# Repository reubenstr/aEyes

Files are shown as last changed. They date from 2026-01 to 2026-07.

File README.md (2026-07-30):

# aEyes

aEyes is a robotic face tracker with a set of six eyes tracking faces as they traverse the scene.

** Work in progress **

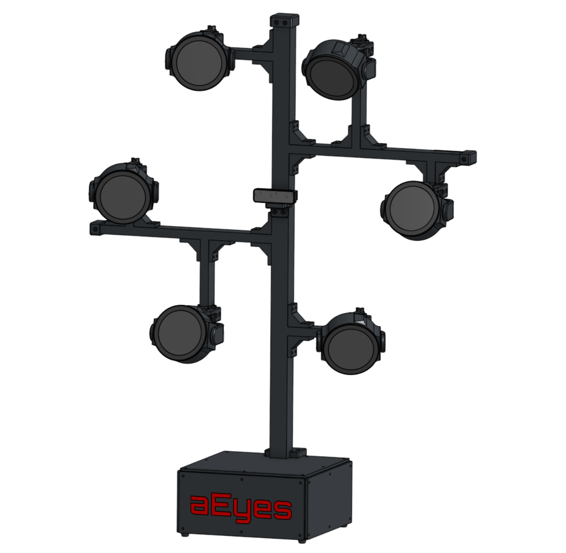
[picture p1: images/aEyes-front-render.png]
Front render


# Simulation

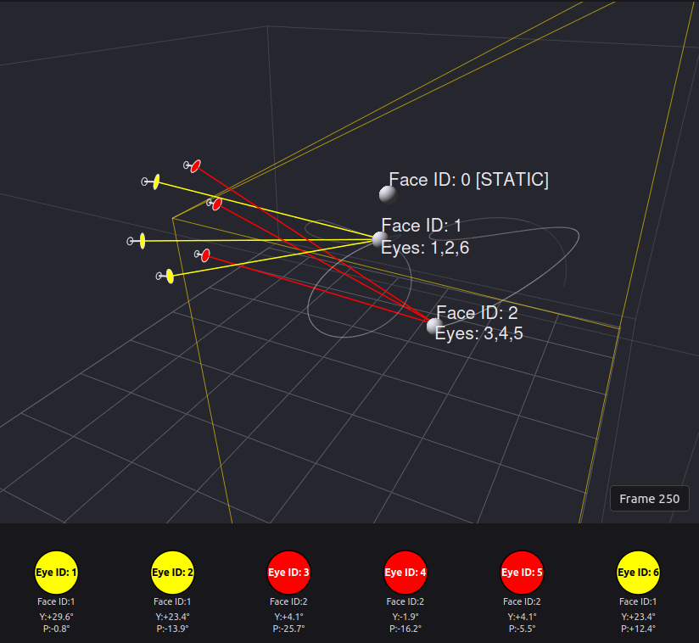
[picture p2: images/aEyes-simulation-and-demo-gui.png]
Simulation and demo GUI


The simulation (using PySide6 + pyqtgraph GUI) generates face positions moving through 3-space with some faces disappearing completely, disappearing and reappearing, or staying static. These faces are then sent through the face tracking, assignment, and eye manager pipeline to generate yaw and pitch of the indivdual eyes. 

# Pipeline

The pipeline is fairly straight forward and the major parts are: **AI Camera Interface → Face Tracker → Eye Manager → Message Publisher → RPi/LCD/Motors**

<figure>
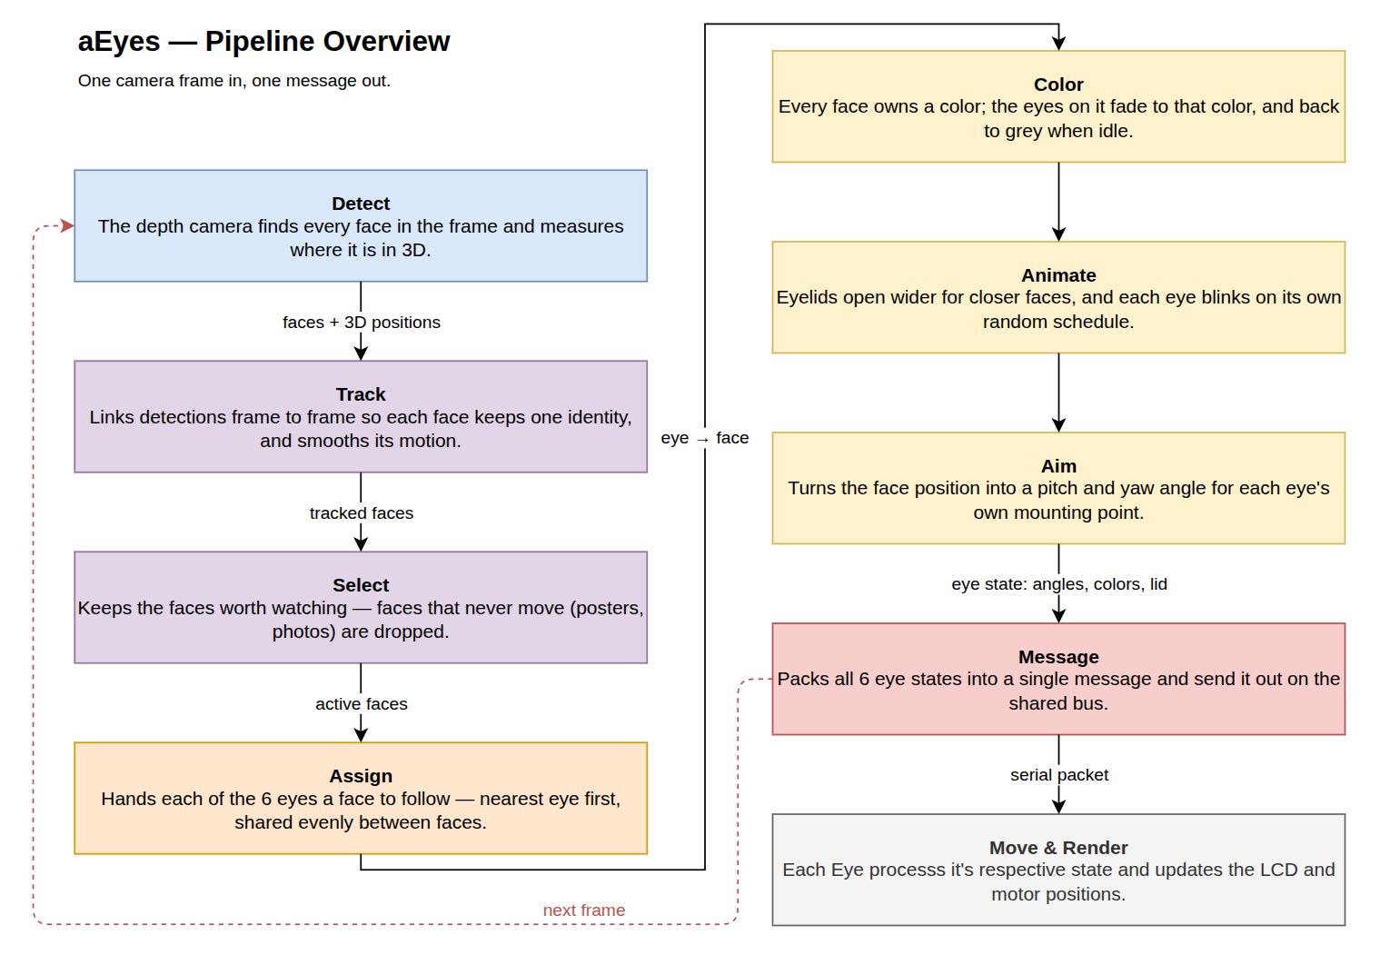
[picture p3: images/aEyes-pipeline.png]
  
  <figcaption align="center">Pipeline Simplified.</figcaption>
</figure>

# System

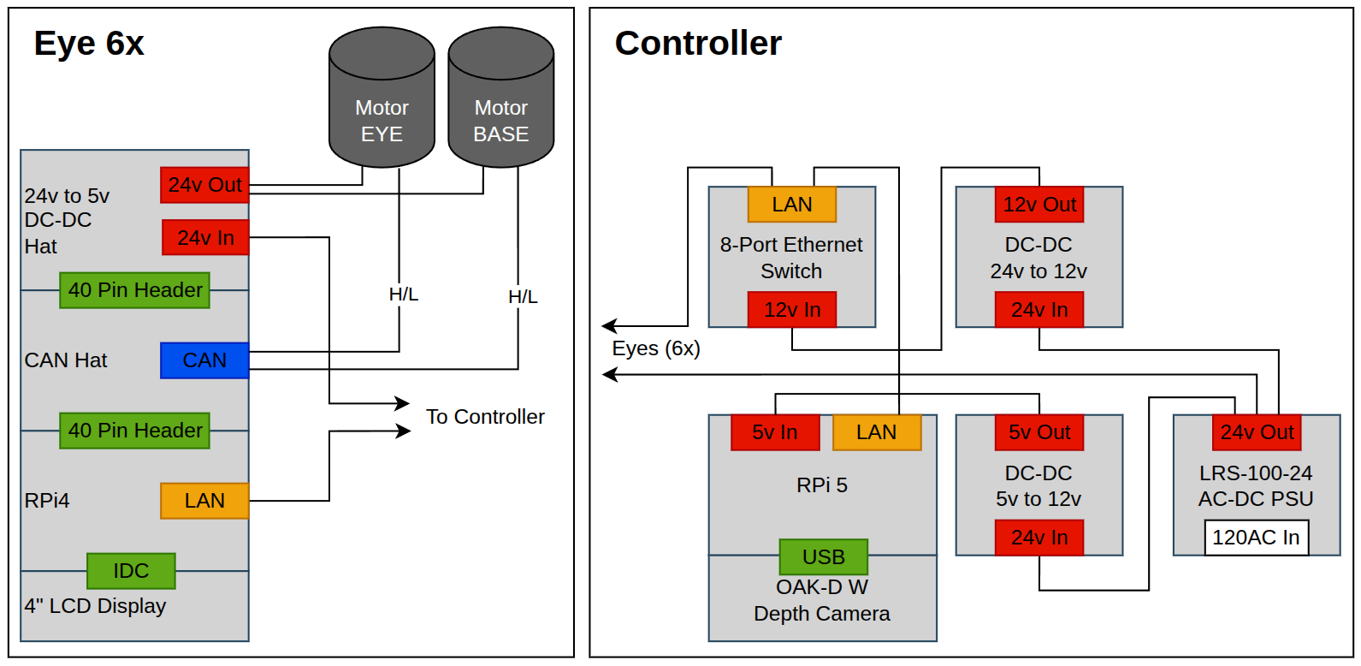
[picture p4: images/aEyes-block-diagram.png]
Block diagram


The system is split into two subsystems: a **Controller** and **6 Eye units**, all connected over a wired Ethernet network.

# Hardware

**Controller**
- Raspberry Pi 5
- OAK-D depth camera (USB)
- Mean Well LRS-100-24 AC/DC PSU (24V)
- DC-DC converter 24V → 12V
- 8-port Ethernet switch

**Eye units (×6)**
- Raspberry Pi 4B
- Waveshare 4" DSI LCD
- Waveshare RS485/CAN Hat
- DC-DC converter hat 24V → 5V
- 1× MG4010E-i10v3 CAN servo motor (yaw)
- 1× MG4005-v2 CAN servo motor (pitch)

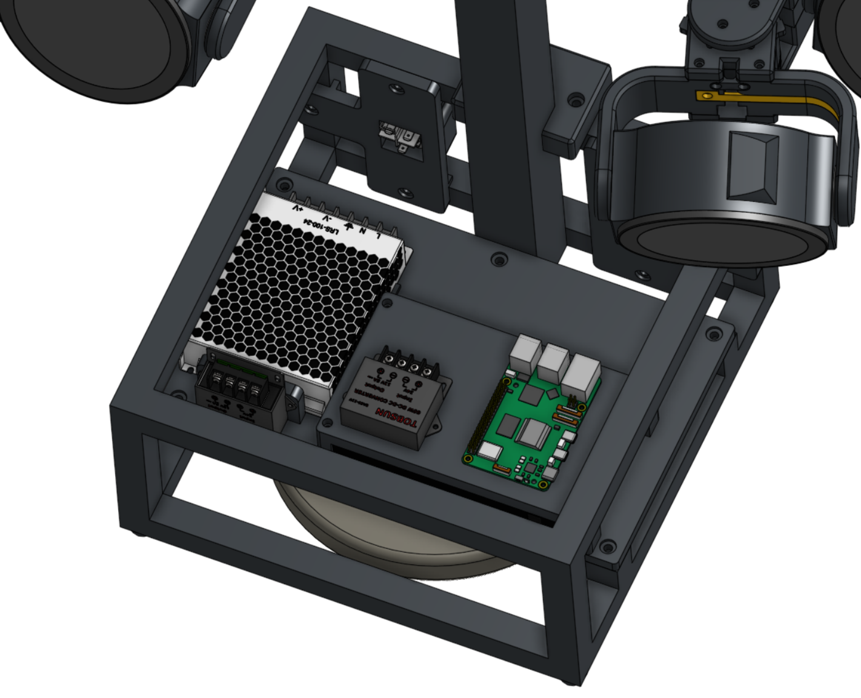
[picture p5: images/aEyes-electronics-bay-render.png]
Electronics bay


# Setup

There are several README's through out the repository for indivdual systems:

- [Controller](controller/README.md)
- [Eye](eye/README.md)
- [Extra Docs](docs/README.md)

# AI Disclosure

Project concept, aesthetic, engineering design, and original code base were conceived and executed by the author.

Portions of this codebase were reviewed, revised, and written with the assistance of Claude Code (Anthropic).

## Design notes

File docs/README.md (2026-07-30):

# Workflow

## Eyes

- Edit eye code on eye1.local
- use aEyes/scripts/pull-eye-code.sh to copy code from eye to controller
- use aEyes/scripts/sync-eye-code.sh to copy eye code from the controller to all eyes
- git commit / push as normal

# After Thoughts

Right now wires are running through the pitch rotation, but since pitch angle is typicall shallow there should not be too much stress on the wires. But, if there are communication issues or power issues, then a slip ring will need to be installed.

The motors are currently very expensive and there are alternatives such as RobStride EL05.

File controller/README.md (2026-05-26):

# Controller

Captures camera data and sends commands to the eyes.

## Installation

### Operating System

SD creation tool:
- https://www.raspberrypi.com/software/

Use the Raspberry Pi creation tool and apply OS customization with the following:
- Operating system: Raspberry Pi OS (64-bit) Desktop (Trixie)
- Hostname: aeyes
- Username/password: aeyes/aeyes
- Wifi credentials 
- Locale settings
- Enable SSH

If customization is not applied, setup the RPi using keyboard/monitor/mouse and use raspi-config to setup hostname, enable SSH, etc.

Update.
```bash
sudo apt update && sudo apt upgrade
```

Generate SSH keys. Use default options.
```bash
ssh-keygen
```

### Repo

Add key to gitlab.

Clone repo
```bash
cd ~
git clone git@github.com:reubenstr/aEyes.git
```

### Setup Controller
```bash
cd ~/aEyes/controller
```
Execute the installation script:
 
- Setups virtual environment
- Installs depenancies
- Apply static IP address to ethernet
- Installs services

```bash
./install.sh
```

## OAK-D W

Setup USB rules:

```bash
echo 'SUBSYSTEM=="usb", ATTRS{idVendor}=="03e7", MODE="0666"' | sudo tee /etc/udev/rules.d/80-movidius.rules
sudo udevadm control --reload-rules && sudo udevadm trigger
```

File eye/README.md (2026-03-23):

# EYE

This code creates the eye graphic and controls the motors.

Executed on each of the eye's Raspberry Pi 4.

## Hardware

- Raspberry Pi 4 B with 4GB RAM (but 2GB will likely work).
- https://www.raspberrypi.com/products/raspberry-pi-4-model-b/

Waveshare 4inch DSI LCD
- https://www.waveshare.com/4inch-dsi-lcd-c.htm
- https://www.waveshare.com/wiki/4inch_DSI_LCD_(C)

Waveshare RS485 CAN Hat
- https://www.waveshare.com/rs485-can-hat.htm
- http://www.waveshare.com/wiki/RS485_CAN_HAT

## Installation

### Operating System

Create a master SD card image that will be cloned for the remaining five RPis. The master will be configured as eye1 to start the process.

SD creation tool:
- https://www.raspberrypi.com/software/

Use the Raspberry Pi creation tool and apply OS customization with the following:
- Operating system: Raspberry Pi OS (64-bit) Desktop (Trixie)
- Hostname: eye1
- Username/password: eye/eye
- Wifi credentials 
- Locale settings
- Enable SSH

Connect the Pi to a keyboard/monitor and boot the Pi. 

Copy the controller's SSH keys to the RPi:
```bash
ssh-copy-id eye@eye1.local
```

Copy the Eye files:
```bash
rsync -av --progress ~/aEyes/eye eye@eye1.local:~/aEyes/
```

SSH into the RPi:
```bash
ssh eye@eye1.local
```

Run the install.sh script:
```bash
cd ~/aEyes/eye
sudo ./install.sh
```

The install script completes the following actions:
- Selects EYE_ID (user selected)
- sets the hostname
- resets the machine ID
- Configs the RPi firmware (overlays for LCD and CAN)
- Creates virtual environment
- Adds EYE_ID to .env
- Adds dev env vars to user's .bashrc
- Installs Python dependancies
- Enables low power mode
- Sets the desktop background image
- Hides the taskbar
- Installs services
- Configures ethernet static IP

Reboot the Pi:
```bash
sudo reboot
```

Verify the DSI LCD operates correctly and the PI is reachable over ethernet.

Turn off WiFi:
```bash
nmcli radio wifi off
```

Shutdown the PI:
```bash
sudo shutdown now
```

## Cloning

Clone the SD card after setup is complete:
```bash
sudo umount /dev/sda*
sudo dd if=/dev/sda of=~/master_eye.img bs=4M status=progress
sudo eject /dev/sda
```

Image the other five SD cards:
```bash
sudo umount /dev/sda*
sudo dd if=~/master_eye.img of=/dev/sda bs=4M status=progress conv=fsync
sudo eject /dev/sda
```

Boot up each RPi and run the install.sh script to setup unique EYE_ID per RPi. Use a keyboard/monitor or boot the RPis one at a time and ssh into eye@eye1.local.

## Mechanical

The main.py script will not initialize the motors if the .motors-zeroed file flag has not been found.

Use the zero.py script to zero the motors. When both motors have been zeroed the script will create the .motors-zered file flag allowing main.py to start

After the hardware is fully assembled and each RPi's software is configured, set the zero position of each motor.
Execute the zero.sh script per RPi.

## Development

ENV vars are required to start GUI on the RPi over SSH:

```bash
export DISPLAY=:0
export XAUTHORITY=/home/pi/.Xauthority
```

Since the main.sh is exected via a service, stop the service prior to manually executing main.sh

```bash
systemctl stop main.service
```

Manually start the eye's software.

```bash
cd aEyes/eye
sudo ./main.sh
```

### Misc. Commands and Notes

```bash
sudo ip link set can0 up type can bitrate 1000000
sudo ifconfig can0 txqueuelen 65536
sudo ifconfig can0 up
```

```bash
sudo systemctl status main.service
sudo journalctl -u main.service -f

```

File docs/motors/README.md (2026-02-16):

# Actuators

Model: MG4005 v2
Model: MG4010E-i10v3

Purchased from the Chinese company LingKong (Shanghai Lingkong Technology Co., Ltd.) also branded as LKMTECH 

LingKong products: http://en.lkmotor.cn/Product.aspx

Aliexpress: https://www.aliexpress.us/item/3256805950420462.html

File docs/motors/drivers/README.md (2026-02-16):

# Drivers

Windows drivers for CP210x USB to UART converter.

Source: https://www.silabs.com/software-and-tools/usb-to-uart-bridge-vcp-drivers?tab=downloads

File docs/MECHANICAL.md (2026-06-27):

# Mechanical

3D printed parts from PETG:
https://www.amazon.com/dp/B0FG3HMCVY

Frame: 2020 V-Slot (Euro Standard will work as well)

## Bolts

Motor to motor extension plate, bearing side: M3x12mm 6x
Motor to motor extension plate, drive side: M2.5x12mm 6x
Motor extention plate to u-channel, drive and bearing side: M3x12mm
2040 motor bracket to motor spacer, motor drive: M3x20mm 3x
2040 motor bracket to motor spacer, M3x8mm 3x

Center wire clip: 2x M3x6mm

U-Channel main: 4x M3x10 mm 
U-Channel wire clip: M3x8mm 
U-Channel stop block: 2x M3x8mm 

Eye:
    RPi hats: 4x M2.5x35 mm
    Motor - mounting side: 4x M3x6mm
    Motor - drive side: 3x M3x12 
    LCD to Front: 4x M4x12mm

Controller:
    Rpi: 4x M2.5x12mm

Base bracket to 2040
    Horiztonal - 8x M5x25mm
    Vertical - 

## Eye
    External
        Vertical: 8x M5x15mm
        Horizontal:  

    Eye Wires:        
        Power wires: 260mm + after sheath
        Ethernet: 250 + after sheath

        Motor wires:       
            Wire sheath - horizontal: 200mm
            Wire sheath - vertical - top: 200mm
            Wire sheath - vertical - bottom: 210mm

            Motor wires - Vertical mounts - 500mm from connector to tips  
            Motor wires - Horiztonal mounts - xxxmm from connector to tips

    Eye 2 starting 540mm wires

## Sheath

Braided sleeve 5mm inner diameter: 280mm (all eyes)

## Eye Positions

Looking at the frame from the observer's perspective: 1 is far left, then count clockwise 2...6 where six is not the lower left.

Network tag colors:
1: red
2: green
3: blue
4: yellow
5: red+green
6: blue+yellow

EYE_ID: Y (left/right), Z (up/down)

## Extrusions
  
See CAD model

## Wires

Motor for vertical orientation:
    Testing: 58cm from end of connectors

### MISC

Current motor wire length: 170mm

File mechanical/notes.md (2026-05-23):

# Mechanical

3D printed parts from PETG:
https://www.amazon.com/dp/B0FG3HMCVY

Frame: 2020 V-Slot (Euro Standard will work as well)

## Bolts

Motor to motor extension plate, bearing side: M3x12mm 6x
Motor to motor extension plate, drive side: M2.5x12mm 6x
Motor extention plate to u-channel, drive and bearing side: M3x12mm
2040 motor bracket to motor spacer, motor drive: M3x20mm 3x
2040 motor bracket to motor spacer, M3x8mm 3x

Center wire clip: 2x M3x6mm

U-Channel main: 4x M3x10 mm 
U-Channel wire clip: M3x8mm 
U-Channel stop block: 2x M3x8mm 

Eye:
    RPi hats: 4x M2.5x35 mm
    Motor - mounting side: 4x M3x6mm
    Motor - drive side: 3x M3x12 
    LCD to Front: 4x M4x12mm

Controller:
    Rpi: 4x M2.5x12mm

Base bracket to 2040
    Horiztonal - 8x M5x25mm
    Vertical - 

## Eye
    External
        Vertical: 8x M5x15mm
        Horizontal:  

    Eye Wires:        
        Power wires: 260mm + after sheath
        Ethernet: 250 + after sheath

        Motor wires:       
            Wire sheath - horizontal: 200mm
            Wire sheath - vertical - top: 200mm
            Wire sheath - vertical - bottom: 210mm

            Motor wires - Vertical mounts - 500mm from connector to tips  
            Motor wires - Horiztonal mounts - xxxmm from connector to tips

    Eye 2 starting 540mm wires

## Sheath

Braided sleeve 5mm inner diameter

1: 
2: 
3: 280mm
4: 
5: 
6: 

## Eye Positions

Looking at the frame from the observer's perspective: 1 is far left, then count clockwise 2...6 where six is not the lower left.

Network tag colors:
1: red
2: green
3: blue
4: yellow
5: red+green
6: blue+yellow

EYE_ID: Y (left/right), Z (up/down)

## Extrusions

2040:
    1x 1150.00mm
    2x 500.00mm
    2x 250.94mm
    2x 216.50mm
    2x 135.47mm
    Note: tolerance -+1mm is OK

2020:
    4x 260mm
    6x 300mm
    4x 100mm

## Wires

Motor for vertical orientation:
    Testing: 58cm from end of connectors

### MISC

current motor wire length: 170mm 

---------------------------------------------------------------

NEW NEW NEW

U-Channel to extension brackets:
    M3x12mm

2040:
    1x 1100.00mm
    2x 440.00mm
    2x 244.62mm
    2x 191.50mm   
    2x 137.81mm
    Note: tolerance -+1mm is OK

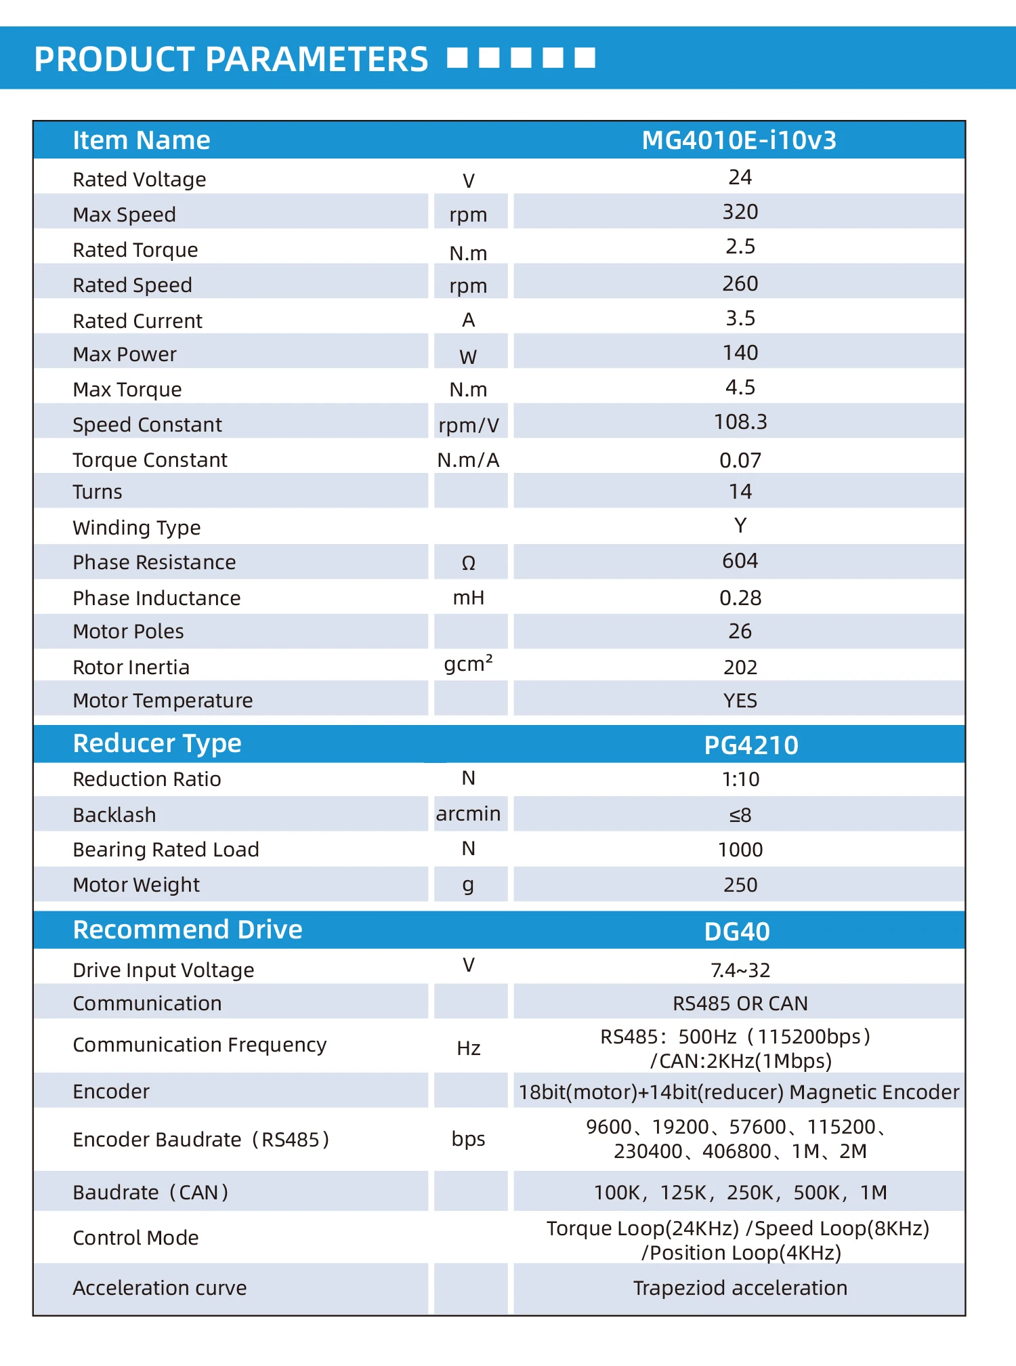
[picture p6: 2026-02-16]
docs/motors/MG4010E-specifications.webp

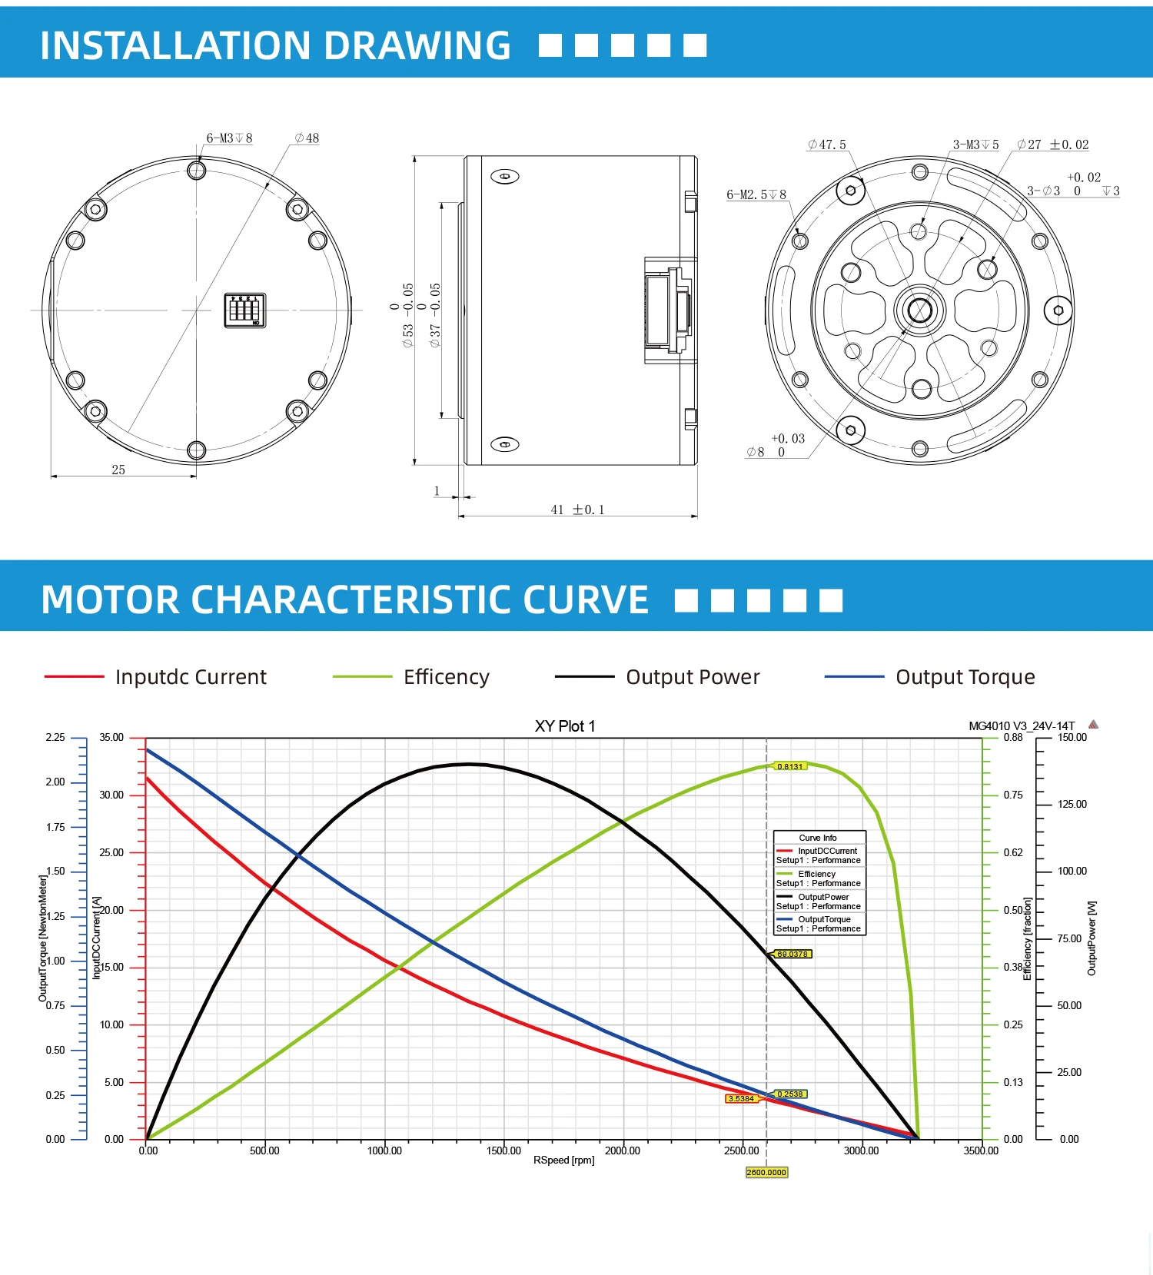
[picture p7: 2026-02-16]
docs/motors/MG4010E-dimensions.webp

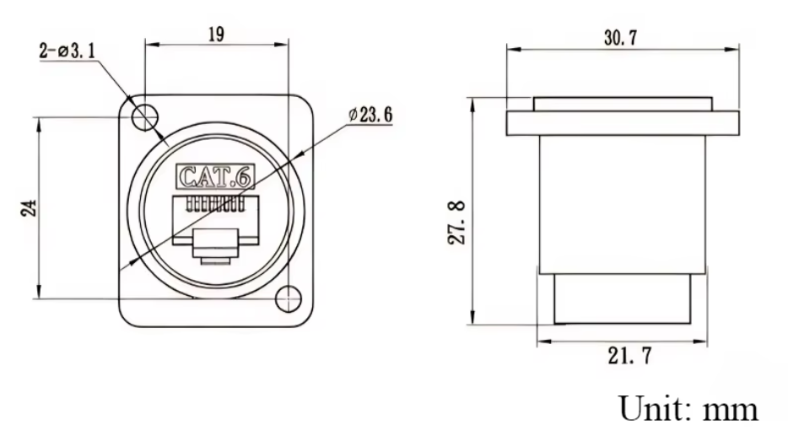
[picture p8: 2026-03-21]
docs/ethernet-bulkhead.png

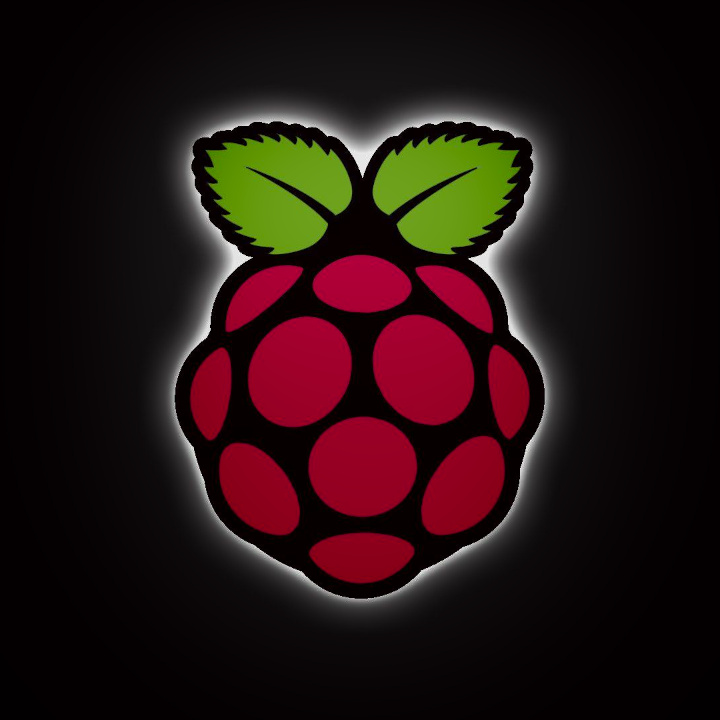
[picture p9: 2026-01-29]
eye/media/desktop.jpg

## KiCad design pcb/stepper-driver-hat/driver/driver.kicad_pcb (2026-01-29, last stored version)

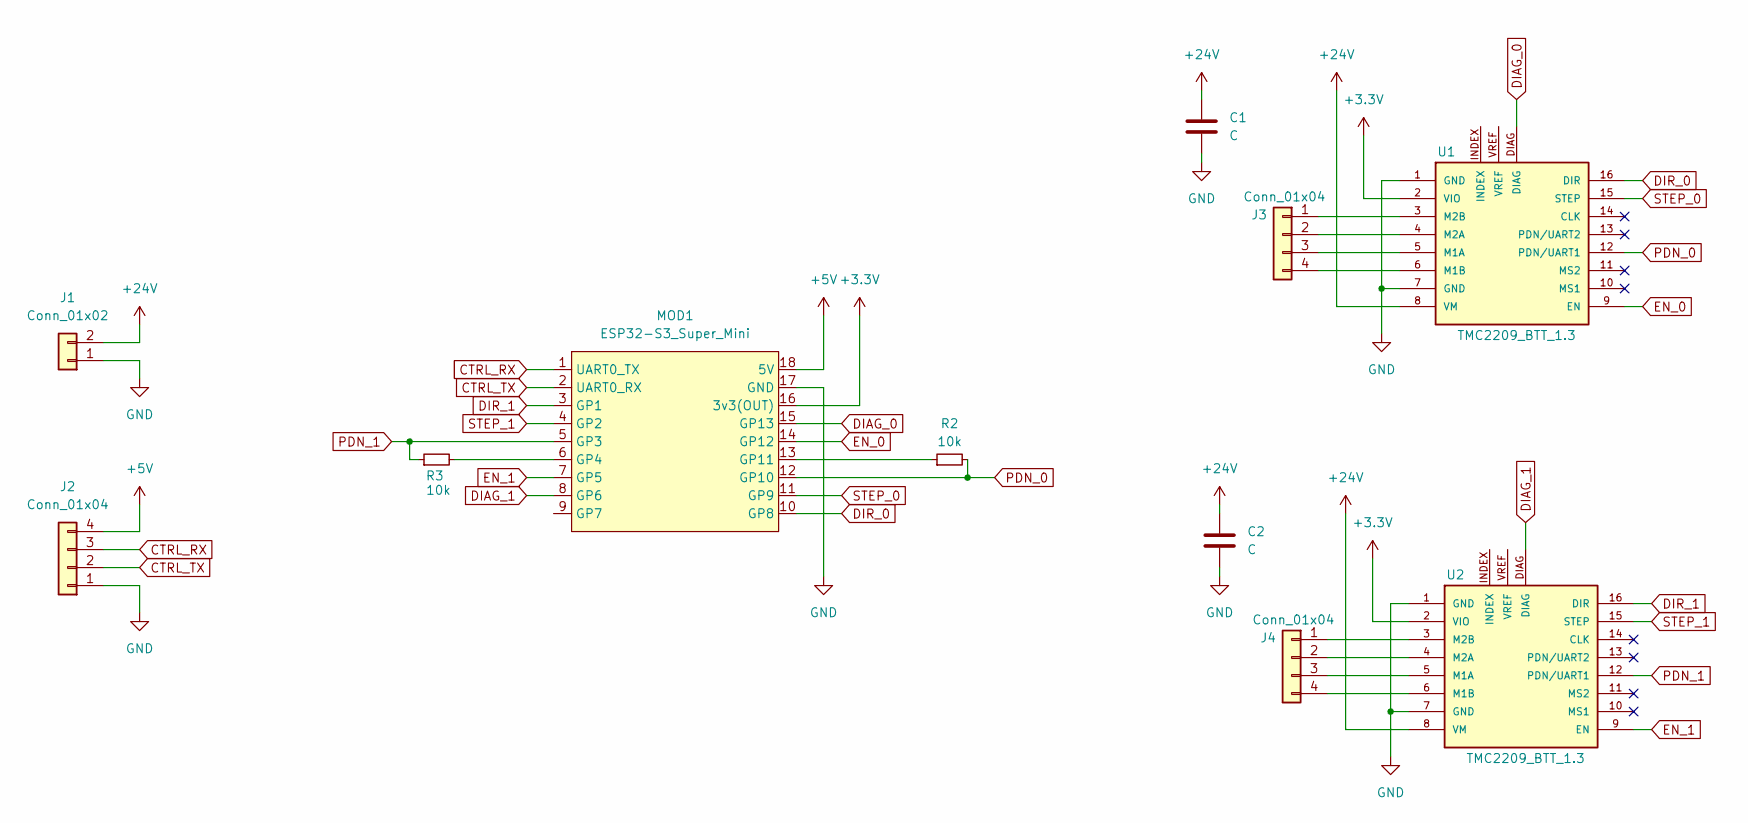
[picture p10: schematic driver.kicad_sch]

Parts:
C1, C2: C; CP_Radial_D10.0mm_P5.00mm
J1: Conn_01x02; PinHeader_1x02_P2.54mm_Vertical
J2, J3, J4: Conn_01x04; PinHeader_1x04_P2.54mm_Vertical
MOD1: ESP32-S3_Super_Mini; ESP32-S3 Super Mini
R2, R3: 10k; R_1206_3216Metric
U1, U2: TMC2209_BTT_1.3; MODULE_TMC2208_TMC2209

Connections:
+3.3V: MOD1.16 (3v3(OUT)), U1.2 (VIO), U2.2 (VIO)
+5V: J2.4, MOD1.18 (5V)
+24V: C1.1, C2.1, J1.2, U1.8 (VM), U2.8 (VM)
CTRL_RX: J2.3, MOD1.1 (UART0_TX)
CTRL_TX: J2.2, MOD1.2 (UART0_RX)
DIAG_0: MOD1.15 (GP13), U1.DIAG
DIAG_1: MOD1.8 (GP6), U2.DIAG
DIR_0: MOD1.10 (GP8), U1.16 (DIR)
DIR_1: MOD1.3 (GP1), U2.16 (DIR)
EN_0: MOD1.14 (GP12), U1.9 (EN)
EN_1: MOD1.7 (GP5), U2.9 (EN)
GND: C1.2, C2.2, J1.1, J2.1, MOD1.17 (GND), U1.1 (GND), U1.7 (GND), U2.1 (GND), U2.7 (GND)
unnamed: J3.1, U1.3 (M2B)
unnamed: J3.2, U1.4 (M2A)
unnamed: J3.3, U1.5 (M1A)
unnamed: J3.4, U1.6 (M1B)
unnamed: J4.1, U2.3 (M2B)
unnamed: J4.2, U2.4 (M2A)
unnamed: J4.3, U2.5 (M1A)
unnamed: J4.4, U2.6 (M1B)
unnamed: MOD1.6 (GP4), R3.2
unnamed: MOD1.13 (GP11), R2.1
PDN_0: MOD1.12 (GP10), R2.2, U1.12 (PDN/UART1)
PDN_1: MOD1.5 (GP3), R3.1, U2.12 (PDN/UART1)
STEP_0: MOD1.11 (GP9), U1.15 (STEP)
STEP_1: MOD1.4 (GP2), U2.15 (STEP)

Board: 2 copper layers, 11 parts (0 on the bottom side), 26 nets, no tracks yet.

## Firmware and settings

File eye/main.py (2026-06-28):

import os
import signal
import sys
import zmq
import json
from eye_renderer import EyeRenderer, TextType
from threading import Thread, Event
from time import sleep, time

from data_types import ControlMessage
from motors.data_types import MotorName, MotorSpeeds
from motors.motors import Motors
from motors.motor_config import get_motor_info, BASE_HOME_INVERSION, EYE_INVERSIONS

SOCKET_ADDRESS = "192.168.5.100"
SOCKET_PORT = 9000
MESSAGE_TIMEOUT_SECONDS = 3.0
CONTROLLER_FPS = 15

class Eye:
    def __init__(self):
        self.eye_id = None
        self.motors = None
        self.socket = None
        self.thread_handle = None
        self.commanded_yaw = 0.0
        self.commanded_pitch = 0.0

    ###############################################################################
    # Initializers
    ###############################################################################

    def init_eye_renderer(self):
        print("[Main] init eye renderer")
        self.eye_renderer = EyeRenderer()
        self.eye_renderer.window.on_close = self.shutdown
        self.eye_renderer.set_text(TextType.INFO, "Waiting for data.")

    def _init_local(self):
        print("[Main] initialize local variables")
        eye_id = os.getenv("EYE_ID", None)
        if eye_id is None:
            self.eye_renderer.set_text(TextType.ERROR, "EYE_ID not found in ENV vars!")
        else:
            self.eye_id = int(eye_id)

    def _init_motors(self):
        print("[Main] initialize motors")

        self.motors = Motors(allow_enable=True)

        if self.eye_id and EYE_INVERSIONS[self.eye_id] is True:
            self.motors.set_inversion_rotation(MotorName.BASE, not self.motors.get_inverse_rotation(MotorName.BASE))
            self.motors.set_inversion_rotation(MotorName.EYE, not self.motors.get_inverse_rotation(MotorName.EYE))
            sleep(0.5) # Allow repolling (recalcuation) of positions that may of been inversed.

        self.motors.enable_all_motors()
        self.home_motors(self.motors)
     

    def _init_socket(self):
        print("[Main] init zmq")
        context = zmq.Context()
        self.socket = context.socket(zmq.SUB)
        address = f"tcp://{SOCKET_ADDRESS}:{SOCKET_PORT}"
        self.socket.connect(address)
        self.socket.setsockopt_string(zmq.SUBSCRIBE, "")
        print(f"[Main] Socket requested at address: {address}")

    ###############################################################################
    # Helpers
    ###############################################################################

    def _flush_socket(self):
        try:
            while True and self.socket is not None:
                self.socket.recv_string(flags=zmq.NOBLOCK)
        except zmq.Again:
            pass

    def ramp_target(self, commanded: float, target: float) -> float:
        CLOSE_DEG = 5.0  # below this → pass-through (fast tracking)
        FAR_DEG = 30.0  # above this → max slowdown
        FAST_DEG_S = 900.0  # deg/sec when close (~pass-through)
        SLOW_DEG_S = 22.5  # deg/sec when far   (smooth slew)
        delta = abs(target - commanded)
        t = max(0.0, min(1.0, (delta - CLOSE_DEG) / (FAR_DEG - CLOSE_DEG)))
        t = 3 * t**2 - 2 * t**3  # smoothstep
        max_step = (FAST_DEG_S + t * (SLOW_DEG_S - FAST_DEG_S)) / CONTROLLER_FPS
        return commanded + max(-max_step, min(max_step, target - commanded))

    ###############################################################################
    # Motor Utilities
    ###############################################################################

    def home_motors(self, motors: Motors):
        """
        Home both motors by moving into the physical endstop and polling for position halt.
        """

        motor_home_target_pos_offset = 180
        motors_to_home = [MotorName.BASE, MotorName.EYE]
        operation_timeout_seconds = 5.0
        home_duration = 0.5  # Time motor is required to be stopped before considered home.
        home_threshold_deg = 0.25
        prev_positions = {motor: motors.get_motor_position(motor) for motor in motors_to_home}
        home_started: dict[MotorName, float | None] = {motor: None for motor in motors_to_home}
        homed = {motor: False for motor in motors_to_home}

        self.eye_renderer.set_text(TextType.INFO, "Homing motors...")

        base_position = motors.get_motor_position(MotorName.BASE)    
        base_home_target_position = (
            -motor_home_target_pos_offset if self.eye_id is not None and BASE_HOME_INVERSION[self.eye_id] is True else motor_home_target_pos_offset
        )    
        eye_home_target_position = motor_home_target_pos_offset
        motors.set_enforce_position_limits(MotorName.BASE, False)
        motors.set_motor_targets(motor_name=MotorName.BASE, speed=MotorSpeeds.SLOW, position=base_position + base_home_target_position)

        eye_position = motors.get_motor_position(MotorName.EYE)
        motors.set_enforce_position_limits(MotorName.EYE, False)
        motors.set_motor_targets(motor_name=MotorName.EYE, speed=MotorSpeeds.SLOW, position=eye_position + eye_home_target_position)

        sleep(0.5)  # Allow motors to begin moving before polling.

        start = time()
        while time() - start < operation_timeout_seconds:
            for motor_name in (m for m in motors_to_home if not homed[m]):
                pos = motors.get_motor_raw_position(motor_name)
                delta = abs(pos - prev_positions[motor_name])
                prev_positions[motor_name] = pos

                if motor_name is MotorName.BASE:
                    print(f"{motor_name}: {pos}")

                started = home_started[motor_name]
                if delta < home_threshold_deg:
                    if started is None:
                        home_started[motor_name] = time()
                    elif time() - started >= home_duration:
                        homed[motor_name] = True
                else:
                    home_started[motor_name] = None

            if all(homed.values()):
                break

            sleep(0.050)

        home_position = get_motor_info(MotorName.BASE).home_position
        raw_pos = motors.get_motor_raw_position(MotorName.BASE)
        pos = motors.get_motor_position(MotorName.BASE)
    
        if self.eye_id is not None and BASE_HOME_INVERSION[self.eye_id] is True:
            offset = -raw_pos - home_position
        else:
            offset = -raw_pos + home_position          

        motors.set_enforce_position_limits(MotorName.BASE, True)
        motors.set_position_offset(MotorName.BASE, offset)
        motors.set_motor_targets(motor_name=MotorName.BASE, speed=MotorSpeeds.SLOW, position=0)

        home_position = get_motor_info(MotorName.EYE).home_position
        raw_pos = motors.get_motor_raw_position(MotorName.EYE)
        offset = -(raw_pos - home_position)
        motors.set_enforce_position_limits(MotorName.EYE, True)
        motors.set_position_offset(MotorName.EYE, offset)
        motors.set_motor_targets(motor_name=MotorName.EYE, speed=MotorSpeeds.SLOW, position=0)
       
        sleep(3)  # Allow motors to reach the home position before exiting. 
    

    ###############################################################################
    # Thread
    ###############################################################################

    def _start(self):
        print(f"[Main] worker thread starting")
        self.exit_event: Event = Event()
        self.thread_handle = Thread(target=self._worker)
        self.thread_handle.start()

    def stop(self):
        print(f"[Main] worker thread stoping")
        if self.thread_handle and self.thread_handle.is_alive():
            self.exit_event.set()
            self.thread_handle.join()

    def _worker(self):
        self.exit_event.clear()
        last_msg_time = time()
        connected = False
        self.eye_renderer.set_text(TextType.INFO, "Waiting for data")
        self._flush_socket()

        while not self.exit_event.is_set():
            if self.socket:
                try:
                    msg_raw = self.socket.recv_string(flags=zmq.NOBLOCK)
                    msg_json = json.loads(msg_raw)

                    if self.eye_id is not None:
                        if str(self.eye_id) not in msg_json:
                            print(f"[Main] WARNING: eye_id {self.eye_id} not found in message.")
                            self.eye_renderer.set_text(TextType.ERROR, f"Eye ID {self.eye_id} not found in message!")
                        else:
                            msg = ControlMessage(**msg_json[str(self.eye_id)])

                            last_msg_time = time()
                            if not connected:
                                connected = True
                                print("[Main] Controller connected.")

                            self.eye_renderer.set_text(TextType.INFO, "")
                            self.eye_renderer.set_radius(msg.radius)
                            self.eye_renderer.set_rotation_deg(msg.rotation_deg)
                            self.eye_renderer.set_eye_lid_position(msg.eye_lid_position)
                            self.eye_renderer.set_iris_color_rgb255(msg.iris_color)
                            self.eye_renderer.set_striation_color_rgb255(msg.striation_color)
                            self.eye_renderer.set_is_cat_eye(msg.is_cat_eye)

                            if self.motors:
                                self.commanded_yaw = self.ramp_target(self.commanded_yaw, msg.yaw)
                                self.commanded_pitch = self.ramp_target(self.commanded_pitch, msg.pitch)
                                self.motors.set_motor_targets(motor_name=MotorName.BASE, speed=MotorSpeeds.FAST, position=self.commanded_yaw)
                                self.motors.set_motor_targets(motor_name=MotorName.EYE, speed=MotorSpeeds.FAST, position=self.commanded_pitch)

                except zmq.Again:
                    if connected and time() - last_msg_time > MESSAGE_TIMEOUT_SECONDS:
                        connected = False
                        print("[Main] Controller disconnected (timeout).")
                        self.eye_renderer.set_text(TextType.ERROR, "Data timeout!")
                except (json.JSONDecodeError, TypeError, KeyError) as e:
                    print(f"[Main] Bad message: {e}")

            sleep(0.005)

    ###############################################################################
    # General
    ###############################################################################

    def _deferred_init(self):
        sleep(0.3)  # Allow pyglet event loop to render first frame
        self._init_local()
        if self.eye_id:
            self._init_motors()
            self._init_socket()
            self._start()

    def run(self):
        self.init_eye_renderer()
        Thread(target=self._deferred_init, daemon=True).start()

        # Blocking
        self.eye_renderer.run()

    def shutdown(self):
        self.stop()
        if self.motors:
            try:
                self.motors.shutdown()
            except Exception as e:
                print(f"[Main] Error shutting down motors: {e}")
        try:
            self.eye_renderer.shutdown()
        except Exception as e:
            print(f"[Main] Error shutting down renderer: {e}")


###############################################################################
# Main Entry
###############################################################################
if __name__ == "__main__":
    eye = Eye()
    signal.signal(signal.SIGTERM, lambda sig, frame: (eye.shutdown(), sys.exit(0)))
    try:
        eye.run()
    except KeyboardInterrupt:
        eye.shutdown()

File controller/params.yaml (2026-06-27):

# Behavioral parameters for the aEyes controller.
# Edit this file to tune the system without touching Python source.
# Physical/geometric constants (eye positions, pivot offsets, FOV) live in config.py.

# ---------------------------------------------------------------------------
# System timing
# ---------------------------------------------------------------------------
system:
  refresh_rate_hz: 15        # Main loop publish rate [Hz]. Higher = more CPU, lower = laggier.

# ---------------------------------------------------------------------------
# Network / ZMQ publisher
# ---------------------------------------------------------------------------
publisher:
  socket_port: 9000          # ZMQ PUB port. Must match SOCKET_PORT on all Pi eye units.
  socket_address: "*"        # Bind address. "*" = all interfaces.

# ---------------------------------------------------------------------------
# Face tracker — matching gate
# ---------------------------------------------------------------------------
tracker:
  base_max_distance: 0.4     # Match gate radius at 1m depth [m].  range: 0.1–1.0
  depth_scale_factor: 0.15   # Gate growth per meter of depth [m/m].  range: 0.0–0.5
  embedding_weight: 0.3      # 0=position-only matching, 1=embedding-only.  range: 0–1

  # Track lifecycle (all in frames)
  min_hits_to_confirm: 30                      # Frames before tentative -> confirmed.  range: 1-60
  min_hits_to_confirm_reacquiring_tracks: 30   # Frames before reacquiring -> confirmed.  range: 1-60
  max_missing_confirmed: 30                    # Frames a confirmed track survives without detection.  range: 5-30
  max_missing_tentative: 5                     # Frames a tentative track survives without detection.  range: 1-5

  # Re-identification
  reid_window_frames: 45     # Frames a lost track is retained for re-ID.  range: 10–60
  reid_max_distance: 1.0     # Spatial search radius for re-ID matching [m].  range: 0.5–2.0

  # Output smoothing
  ema_alpha: 0.4             # EMA smoothing on output position. Lower = smoother, laggier.  range: 0–1
  embedding_ema_keep: 0.7    # Weight of existing embedding in running average.  range: 0–1
                             # New embedding weight = 1 - embedding_ema_keep.

  # Static-face detection — faces whose rolling-max Kalman speed stays below
  # static_speed_thresh_mps for static_window consecutive matched frames are
  # classified as static and excluded from eye assignment.
  static_window: 1000            # Rolling velocity window length [frames].  range: 30–1000
  static_speed_thresh_mps: 0.15  # Max speed to be considered static [m/s].  range: 0.01–1.0

# ---------------------------------------------------------------------------
# Kalman filter (3D constant-velocity)
# ---------------------------------------------------------------------------
kalman:
  process_noise: 0.1         # Process noise (q). Higher = tracks react faster but noisier.
  measurement_noise_xy: 0.05 # X/Y position measurement noise [m]. Lower = trust sensor more.
  measurement_noise_z: 0.20  # Depth measurement noise [m]. Higher = trust depth less.

# ---------------------------------------------------------------------------
# Eye assigner
# ---------------------------------------------------------------------------
assigner:
  assign_interval_s: 0.5     # Min seconds between assigning extra eyes to already-covered faces.

# ---------------------------------------------------------------------------
# Eye manager — animation
# ---------------------------------------------------------------------------
eye_manager:
  color_in_rate: 2.0         # Lerp speed toward face color [units/s]. Higher = faster.
  color_out_rate: 4.0        # Lerp speed back toward grey [units/s].
  blink_rate: 1.0            # Blink animation speed on new face assignment [blinks/s].

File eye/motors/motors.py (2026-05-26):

#!/usr/bin/env python
import os
import can
import sys
import traceback
import subprocess
from time import time, sleep
from rich import print  # Overrides print and injects colors
from threading import Thread, Event, Lock
from typing import Dict, List

from motors.motor import Motor
from motors.motor_config import motor_config
from motors.data_types import CanInfo, MotorZeroInfo, Status, MotorName


"""
    Controls a collection of MG4010E-i10v3 actuators on a multiple CAN bus networks.
"""

class Motors:
    def __init__(self, allow_enable: bool):
        self.allow_enable: bool = allow_enable
        self.tag: str = "Motors"

        self.thread_handle = None
        self.exit_event = Event()
        self.data_lock = Lock()

        self.motors_enabled: bool = False
        self.motor_enable_sequence_delay_seconds: float = 0.250
        self.motor_disable_sequence_delay_seconds: float = 0.250     

        self.min_loop_rate_seconds: float = 0.010

        can_channels = list({motor.can_channel for motor in motor_config() if motor.allow_motion or motor.allow_comms})
        self.can_infos: Dict[str, CanInfo] = {}
        for can_channel in can_channels:
            self.can_infos[can_channel] = CanInfo(
                can_channel=can_channel,
                bus=None,
                status=Status.STANDBY,
                thread_handle=None,
                exit_event=Event(),
                lock=Lock(),
            )
        self.init_can_buses(self.can_infos)

        self.motors: Dict[str, Motor] = {}
        self.target_positions: Dict[str, float] = {}
        self.target_speeds: Dict[str, int] = {}

        default_speed: int = 250

        for motor in motor_config():
            if motor.can_channel in can_channels:
                self.motors[motor.name] = Motor(
                    name=motor.name,
                    motor_id=motor.id,
                    min_position=motor.min_position,
                    max_position=motor.max_position,
                    inverse_rotation=motor.inverse_rotation,
                    allow_comms=motor.allow_comms,
                    allow_motion=motor.allow_motion,
                    can_channel=motor.can_channel,
                    bus=self.can_infos[motor.can_channel].bus,              
                )
                self.target_positions[motor.name] = 0  # Will be set during enable.
                self.target_speeds[motor.name] = default_speed

        self.worker_startup_timeout_seconds: float = 5.0    
        self._start()

    ###############################################################################
    # CAN
    ###############################################################################

    def init_can_buses(self, can_infos: Dict[str, CanInfo]):

        self.deinit_can_buses(can_infos)

        for can_info in can_infos.values():
            print(f"[{self.tag}] upping {can_info.can_channel} interface")

            result = subprocess.run(
                f"sudo ip link set {can_info.can_channel} up type can bitrate 1000000",
                shell=True,
                capture_output=True,
                text=True,
            )

            if result.returncode == 0:
                print(f"[{self.tag}] initializing {can_info.can_channel}  bus")
                try:
                    # USB CAN using this firmware:
                    # https://canable.io/getting-started.html#alt-firmware
                    # https://canable.io/updater/canable2.html
                    can_info.bus = can.interface.Bus(interface="socketcan", channel=can_info.can_channel, bitrate=1000000)
                except:
                    print(f"[{self.tag}] error, unable to init {can_info.can_channel}!")
                    can_info.status = Status.ERROR
                    continue

            else:
                print(f"[{self.tag}] error, failed to up {can_info.can_channel}!")
                can_info.status = Status.ERROR
                continue

            sleep(1)     
            can_info.status = Status.ACTIVE

    def deinit_can_buses(self, can_infos: Dict[str, CanInfo]):
        for can_info in can_infos.values():
            # if can_info.status == Status.ACTIVE:
            print(f"[{self.tag}] deinitializing {can_info.can_channel}")
            try:
                if can_info.bus:
                    can_info.bus.shutdown()
                    can_info.status = Status.STANDBY
            except:
                print(f"[{self.tag}] error deinitializing {can_info.can_channel}!")

            print(f"[{self.tag}] downing {can_info.can_channel} interface")
            os.system(f"sudo ifconfig {can_info.can_channel} down")

    ###############################################################################
    # Per Motor
    ###############################################################################

    def set_zero_to_current_position(self, motor_name: str):
        """Zero requires power cycle to take effect!"""        
        motor = self.motors[motor_name]
        success = motor.cmd_set_zero_to_current_pos()     
        return success

    ###############################################################################
    # All Motors
    ###############################################################################

    def enable_all_motors(self):
        max_attempts = 3
        start = time()
        self.acquire_can_locks()
        for motor in self.motors.values():
            if self.allow_enable and motor.allow_motion:
                print(f"[{self.tag}] enabling motor: {motor.name}")
                attempt = 0
                while True:
                    if motor.cmd_motor_on():
                        break
                    else:
                        attempt += 1
                        print(f"[{self.tag}][ALL] error, failed to enable {motor.name}, attempt number {attempt}!")
                        if attempt > max_attempts:
                            self.motors_enabled = False                         
                            self.release_can_locks()
                            return False
                        sleep(self.motor_enable_sequence_delay_seconds)

                sleep(self.motor_enable_sequence_delay_seconds)
        print(f"[{self.tag}][ALL] enable all motors on completed, time: {time() - start:0.3f}")
        self.motors_enabled = True     
        self.release_can_locks()
        return True
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

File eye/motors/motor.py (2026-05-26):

import os
import can
from rich import print
from can.interface import Bus
from typing import Optional

from .data_types import MotorName

"""
    Motor:
        mg4010e-i10-v3

    Info link:
        https://wiki.openelab.io/lkmtech/mg4010e-i10-v3-dual-encoder-robot-motor

    Docs:
        See docs directory for datasheets, drawings, etc.

    Basic specs:
        Rated torque: 2.5Nm
        Rated speed: 260rpm
        Rated voltage: 24V
        Rated current: 3.5A
        Communication: CAN
        Encoders: Dual (motor shaft and output shaft)
        Gearbox: 1:10 reduction ratio
        Weight: 250g

    Hardware driver notes:
        Does not contain a min and max position, there software is required to check for physical limits.
        
        CAN is not able to set the torque limit, speed limit, etc. Only the UART interface is capable
        of setting these parameters. The torque limit is used to create 'compliance'. A best guess is implemented.
    
    Software driver Notes:
        Upon startup the motor driver reports angles 0 to 360 degrees.
        To prevent issues of wrong initial directions, this library
        uses a -180 to 180 convention.
        Start up angles > 180 flag an offset to match the desired convention.

        Pid params are saved in RAM and must be applied after each power cycle.
"""


class Motor:
    def __init__(
        self,
        name: MotorName,
        motor_id: int,
        min_position: float,
        max_position: float,
        inverse_rotation: bool,
        allow_comms: bool,
        allow_motion: bool,
        can_channel: str,
        bus: Bus,
    ):
        self.name: MotorName = name
        self.motor_id: int = motor_id
        self.min_position: float = min_position
        self.max_position: float = max_position
        self.inverse_rotation: bool = inverse_rotation
        self.allow_comms: bool = allow_comms
        self.allow_motion: bool = allow_motion
        self.can_channel: str = can_channel
        self.bus: Bus = bus

        self.tag = f"[Motor][{name}]"
        self.prints_enabled: bool = False

        # Motor states (from motor driver):
        self.temperature: int = 0
        self.voltage: float = 0
        self.current: float = 0
        self.motor_speed: int = 0
        self.encoder_position: int = 0
        self.raw_position_degrees: float = 0
        self.position_degrees: float = 0

        # Motor fault states (from motor driver):
        self.under_voltage_protection: bool = False
        self.over_voltage_protection: bool = False
        self.over_temperature_protection: bool = False
        self.lost_input_protection: bool = False

        # Motor states:
        self.enabled: bool = False
  
        # Communication states:
        self.send_error: bool = False
        self.reply_timeout_seconds: float = 0.050
        self.reply_timeout_count: int = 0

        # Driver config:
        self.angle_pid_kp: int = 5  # Position loop, default: 100
        self.angle_pid_ki: int = 5  # Position loop, default: 100
        self.speed_pid_kp: int = 50  # Speed loop, default: 50
        self.speed_pid_ki: int = 40  # Speed loop, default: 40
        self.iq_pid_kp: int = 50  # Torque loop, default: 50
        self.iq_pid_ki: int = 50  # Torque loop, default: 50

        # Other config:
        self.position_offset: float = 0.0
        self.max_reply_timeouts_allow: int = 3
        self.enforce_position_limits: bool = True

        self.ARBITRATION_BASE_OFFSET: int = 0x140

    ###############################################################################
    # Operations
    ###############################################################################

    def op_can_send_message(self, motor_id: int, data: list):
        try:
            identifier = self.ARBITRATION_BASE_OFFSET + motor_id
            if self.prints_enabled:
                print(f"{self.tag} sending message, bus={self.bus.channel_info}, motor_id={motor_id}, arbitration_id=0x{identifier:X}, data={data}")
            msg = can.Message(is_extended_id=False, arbitration_id=identifier, data=data)
            self.bus.send(msg)
            self.send_error = False
            return True
        except Exception as e:
            self.send_error = True
            if self.prints_enabled:
                print(f"{self.tag}[op_can_send_message] {type(e).__name__} {e}")
            return False

    def op_wait_for_reply(self) -> Optional[can.Message]:
        reply = self.bus.recv(self.reply_timeout_seconds)
        if reply is None:
            self.reply_timeout_count += 1
        else:
            self.reply_timeout_count = 0
        return reply

    ###############################################################################
    # Commands
    ###############################################################################

    def cmd_motor_on(self):
        if not self.op_can_send_message(self.motor_id, [0x88, 0, 0, 0, 0, 0, 0, 0]):
            return False
        reply = self.op_wait_for_reply()
        success = reply and self.motor_id == reply.arbitration_id - self.ARBITRATION_BASE_OFFSET
        if success:
            self.enabled = True
        return success

    def cmd_motor_off(self):
        if not self.op_can_send_message(self.motor_id, [0x80, 0, 0, 0, 0, 0, 0, 0]):
            return False
        reply = self.op_wait_for_reply()
        success = reply and self.motor_id == reply.arbitration_id - self.ARBITRATION_BASE_OFFSET
        if success:
            self.enabled = False
        return success

    def cmd_motor_stop(self):
        if not self.op_can_send_message(self.motor_id, [0x81, 0, 0, 0, 0, 0, 0, 0]):
            return False
        reply = self.op_wait_for_reply()
        return reply and self.motor_id == reply.arbitration_id - self.ARBITRATION_BASE_OFFSET

    def cmd_clear_motor_errors(self):
        if not self.op_can_send_message(self.motor_id, [0x9B, 0, 0, 0, 0, 0, 0, 0]):
            return False
        reply = self.op_wait_for_reply()
        return reply and self.motor_id == reply.arbitration_id - self.ARBITRATION_BASE_OFFSET

    def cmd_set_zero_to_current_pos(self):
        if not self.op_can_send_message(self.motor_id, [0x19, 0, 0, 0, 0, 0, 0, 0]):
            return False
        reply = self.op_wait_for_reply()
        return reply and self.motor_id == reply.arbitration_id - self.ARBITRATION_BASE_OFFSET

    def cmd_set_pid_to_ram(self, angle_kp: int, angle_ki: int, speed_kp: int, speed_ki: int, iq_kp: int, iq_ki: int):
        """
        Sets PID parameters to RAM; invalid upon power cycle.
        """
        if not self.op_can_send_message(self.motor_id, [0x34, 0, angle_kp, angle_ki, speed_kp, speed_ki, iq_kp, iq_ki]):
            print("[Motor] failed to send pid to motor!")
        reply = self.op_wait_for_reply()
        return reply and self.motor_id == reply.arbitration_id - self.ARBITRATION_BASE_OFFSET
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

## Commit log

2026-01-22 sauron working - but going to revert to eye
    [main.py]
2026-01-24 pcb schem update
    [stepper-driver-hat.kicad_pcb, stepper-driver-hat.kicad_sch]
2026-01-25 motor test
2026-01-27 esp32 comm started
    [driver.kicad_pcb, driver.kicad_sch, stepper-driver-hat.kicad_sch]
2026-01-27 stepper driver update
2026-01-28 frag cleanup, better blink, cat eye shadow fix
    [controller.py]
2026-01-29 add motor commands to messages
2026-01-29 firmeware update
    [driver.kicad_pcb, driver.kicad_sch]
2026-02-02 can motor test success
2026-02-16 update motors
2026-02-17 remove old firmware, etc.
    [driver.kicad_pcb, driver.kicad_sch, stepper-driver-hat.kicad_pcb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]
2026-02-25 building classes, data flowing crudely
2026-02-26 clean up; pre add gimbal arm transform
2026-02-26 gimbal arm t added and appears to be working
2026-03-10 managers: refactor EyeState, add striation color, blink, and Python 3.12 type syntax
    - Rename color/target_color to iris_color/target_iris_color
    - Add striation_color/target_striation_color (defaults to grey)
    - Replace face_ids list with singular face_id (one face per eye)
    - Simplify EyeAssignments type to dict[EyeId, FaceId | None]
    - Add eye_lid blink animation on new face assignment (BLINK_RATE)
    - Fix eye_lid convention: 0.0=closed, 1.0=open; default to open
    - Replace gimbal references with eye in comments/docstrings
    - Replace Optional[X] with X | None throughout; drop typing imports
    - Add CLAUDE.md
    [data_types.py, eye_manager.py, plot_tracks.py]
2026-03-10 eye: clean up eye.frag shader
    - Remove dead highlight block and unused length2 function
    - Inline mainImage into main (Shadertoy convention not needed here)
    - Rename m -> FBM_ROT with explanatory comment
    - Replace reused f variable with named locals (splotch, striation, pupil, vignette)
    - General formatting and comment cleanup
    [data_types.py, plot_tracks.py]
2026-03-10 plot_tracks: add gaze rays, yaw/pitch display, and bounded face detections
    - Refactor managers/ files to controller/ root (rename)
    - Conversions: remove RealSense optical conversion, assume system-frame input
    - EyeState: add yaw/pitch fields; EyeManager computes gimbal angles per frame
    - plot_tracks: draw yaw/pitch-driven gaze rays from each eye to assigned face
    - plot_tracks: show live Y:/P: angles in eye icon strip
    - plot_tracks: replace linear-drifting face_c/face_d with bounded oscillations
    - Add matrix_utils.py with homogeneous transform helpers
    [conversions.py, data_types.py, eye_manager.py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]
2026-03-10 plot_tracks: update bounds, aspect ratio, labels, and grid
    - Simulated face bounds expanded to x[1,3], y[-2,2], z[-1,1]
    - Axis limits and box_aspect updated for true 1:1:1 scaling
    - Removed grid and grey pane walls
    - Face ID and eye label font sizes increased to 8
    - Face ID text offset raised above sphere (+0.06 Z)
    - Eye icon strip: added yaw/pitch readouts per eye
    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
2026-03-10 eye_assigner: fix rebalance threshold to actually converge to even load
    max_allowed was ceil(ideal) + 1, which with 6 eyes and 2 faces allowed
    a 4/2 split without triggering rebalance. Removing the + 1 ensures
    convergence to the true ceil(ideal) distribution (e.g. 3/3).
    [eye_assigner.py]
2026-03-11 eye/install: fix bugs, add machine-id regen, and update README
    install.sh fixes:
    - move apt install before venv creation (python3-venv ordering bug)
    - fix $HOME → $USER_HOME in systemd service file paths
    - fix WorkingDirectory/ExecStart path: aEyes/src/eyes → aEyes/eye
    - replace systemctl stop+start with restart (avoids crash on first install)
    - move error trap to top of script
    - remove redundant sudo (script runs as root)
    - add python3-venv and apt update to dependency install
    - add machine-id regeneration to prevent DHCP/ARP conflicts after SD clone
    README: fix typos, remove redundant setup steps, correct hostname format
    [config.py, conversions.py, data_types.py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]
2026-03-22 add motor not zeroed protection
2026-03-22 motor zero guard, service display fix, rsync and restart improvements
    - Require .motors-zeroed file before enabling motors in main.py
    - Add DISPLAY/XAUTHORITY env vars to systemd service unit
    - Exclude __pycache__ and *.pyc from rsync scripts
    - Restart main.service on each Pi after successful push
    - Add motors shutdown log message
    [main.py, motors.py]
2026-03-23 add EYE motor homing on startup with endstop detection and position offset
    - Home EYE motor against physical endstop on init, detect stop via position
    change threshold with timeout, then apply calibrated position_offset
    - Add position_offset field and set_position_offset() method to Motor
    - Fix cmd_set_angle_and_speed: apply inversion before offset (correct order)
    - Apply position_offset in req_position to keep reported position in logical space
    - Rename apply_position_offset -> apply_180_offset for clarity
    - Fix motor_list find: use next() instead of non-existent list.find()
    - Fix get_motor_position() typo and missing motor_name argument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
    [eye_renderer.py, interfaces.py, main.py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]
2026-03-28 eye inits and fixes
    [main.py]
2026-03-28 fix motor homing bug
    [data_types.py, main.py, motor.py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]
2026-03-28 full pipeline working (jetson)
2026-03-28 motor tweaks
2026-03-28 update sigterm on main.py for eye to prevent shutdown issues
    [main.py]
2026-03-29 motor speed ramping applied first pass
2026-03-29 add static face filter
2026-05-23 update motor homing
2026-05-24 add motor pos test script
2026-05-24 update motor - cleaning up inverts, etc.
    [can-test.py, main.py, motor.py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]
2026-05-24 homing fixes
2026-05-25 motor driver various cleanups
2026-05-25 fix motor homing calculation issues
    [data_types.py, main.py, motor_config.py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]
2026-05-26 oak camera started
2026-05-26 reconnect detections with new camera
2026-05-26 spat calc device move
2026-05-26 update frame params
2026-06-27 detector.py intellisense errors cleanup
    [params.yaml]
2026-06-27 shutdown button started
2026-10-19 update eye motor code to provide info
2026-10-19 motor traj update - under test
2026-10-30 eye motor code fix
2026-10-30 eye motor param updates
2026-10-31 motor lock fix
